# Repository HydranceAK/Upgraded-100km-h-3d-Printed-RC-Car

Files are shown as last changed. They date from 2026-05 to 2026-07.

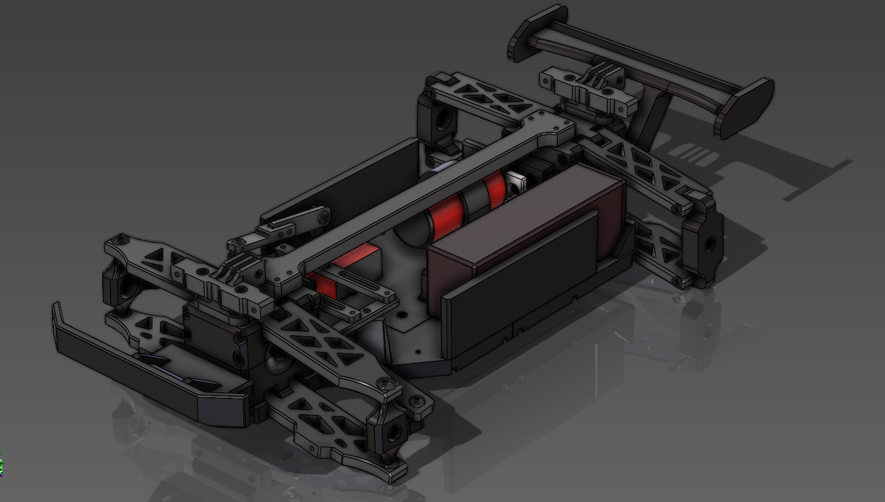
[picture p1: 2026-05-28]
Images/Screenshot 2026-05-28 100129.png

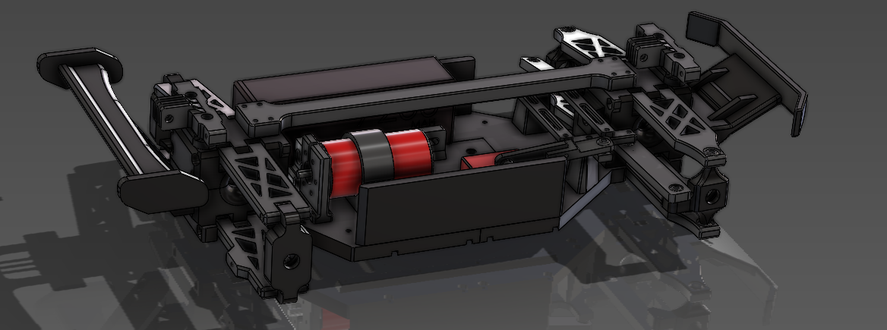
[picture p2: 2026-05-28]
Images/Screenshot 2026-05-28 100137.png

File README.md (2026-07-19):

Designed and engineered by Hydrance.

This is my final and best version of my 3d printed RC Car series. Upgraded with metal differentials, metal axles, improved suspension, 
larger frame, more space for adjustments, and an overall polished and improved design, this will likely be my final attempt at making the perfect 3d printed RC Car.  

This RC Car is nearly have the price to any premade online rc car you will find. This car comes with perks of being completely customizable. All source files are provided for completely free, you can make any changes and share for others to use. You can buy replacements parts for dirt cheap, and print anything for under $0.50 if your car breaks.

Instruction & Assembly Manual: [**LINK TO MANUAL**](https://fanciful-zabaione-62d97d.netlify.app/)

Youtube Video: [**LINK TO YOUTUBE CHANNEL**](https://www.youtube.com/@HydranceYT)

Solidworks and source files are available for purchase on my website: COMING SOON 

_****STABLE RELEASE 3.0****_
_****BETA RELEASE 4.0****_

Patch notes:

- Suspension arms changed, much bulkier, double width
- Wheel hubs adjusted for quality
- Minor changes in axle supporter and battery stopper
- Frame lengthend and thickened
- Stability and strength improved

History of Releases:

- V1 May 21st 2026
- V1.5 May 25th 2026
- V2 May 27th 2026
- V3 June 21st 2026 (only on makerworld)
- V4 June 29th 2026 (UNSTABLE RELEASE, DO NOT PRINT)

Features

-4WD Drivetrain

-Top Speed: - 100km/h (untested as of today)

-Independent Suspension

-Fully metal drive train

-TPU parts for flexible components (tires, dampening mounts, impact zones)

-PETG parts for strong structural elements (chassis, arms, mounts)

**Printing Notes**

-TPU recommended for flexible and shock-absorption components

-PETG recommended for strength, heat resistance, and rigidity

-Everything can be printed on Bambu Lab a1 (0.4 or 0.6 nozzle)

-Hardware, electronics, and drivetrain components sourced Amazon and AliExpress

**Tools you will need**

-Sodering machine or lighter to hear threaded inserts
-Screw Driver
-Cutters
-Pliers

**Disclaimer**

This project is provided for personal use only.

You may not sell, redistribute, upload, or copy this design without direct permission from the creator.

I am not responsible for any damage, injury, or misuse involving this design, its assembly, or its operation.

Operate RC vehicles safely and responsibly.

**Contact**

For permissions, questions, or collaboration, contact me at:

Email: abdusamaku@gmail.com

YouTube: https://youtube.com/@HydranceYT







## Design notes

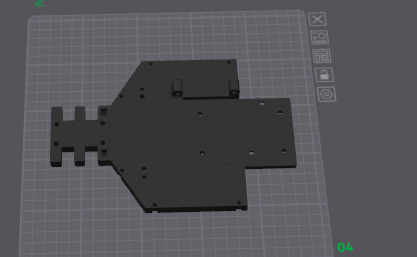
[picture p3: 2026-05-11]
Images/Screenshot 2026-05-07 212240.png

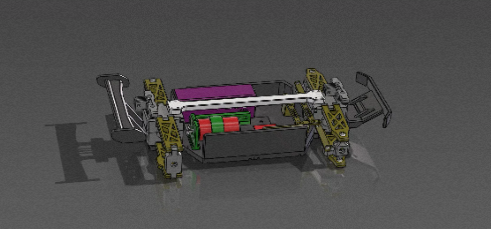
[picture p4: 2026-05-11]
Images/Screenshot 2026-05-11 104807.png

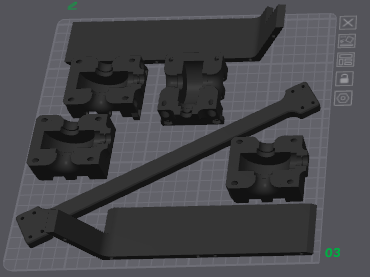
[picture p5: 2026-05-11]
Images/Screenshot 2026-05-07 212237.png

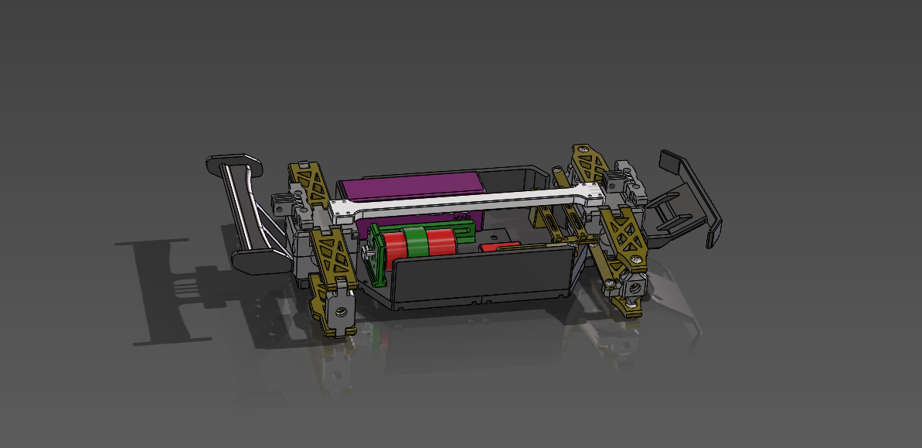
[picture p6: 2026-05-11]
Images/Screenshot 2026-05-07 211917.png

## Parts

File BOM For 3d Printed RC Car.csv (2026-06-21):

Part Name | Quantity | Link | Link 2 | Unit Price (cheaper of the two links) | Total (CAD)
HSP 1:10 RC Car Front Differential Gearbox Assembly for 94111 94123 02051 02030 03015 Models | 1 | https://www.aliexpress.com/item/32785144165.html |  | $11.50 | $11.50
HSP 1:10 RC Car Rear Differential Gearbox Assembly Upgrade Set for 94111 94123 02051 02030 03015 Model | 1 | https://www.aliexpress.com/item/32785144165.html |  | $12.50 | $12.50
Metal 08029 Dogbones 89.5 Drive Shaft | 1 | https://www.amazon.ca/dp/B08SBXVM3T | https://www.aliexpress.com/item/1005005871803520.html | $7.00 | $7.00
Hex Mounts (12mm, 5mm thickness) | 1 | https://www.aliexpress.com/item/1005005581727925.html? |  | $6.00 | $6.00
170mm Central Drive Shaft With Cups | 1 | https://www.aliexpress.com/item/1005002029883656.html | https://www.aliexpress.com/item/1005004008554769.html | $6.00 | $6.00
Spur Gears (21T & 64T) 11184 Steel Metal Spur HSP Car | 1 | https://www.aliexpress.com/item/32852070235.html? | https://www.aliexpress.com/item/1005008726909208.html | $5.00 | $5.00
Motor (2850KV 3670) 3-4S Lipos | 1 | https://www.amazon.ca/GoolRC-S3670-2850KV-Brushless-Sensorless/dp/B08YD792LM |  | $50.00 | $50.00
ESC (120A) 2-3s (60km/h) 2-4s (100km/h) | 1 | https://www.aliexpress.com/item/1005007728846589.html |  | $30.00 | $30.00
Threaded Inserts (m2, m3, m4 sets) | 1 | https://www.amazon.ca/Heat-Set-Threaded-Inserts-Printing-Components/dp/B0DCJ4MXCM |  | $14.00 | $14.00
M4 Screw Assortment | 1 | https://www.amazon.ca/Hilitchi-300-Piece-Phillips-Assortment-stainless/dp/B01N4HPO2D |  | $12.00 | $12.00
M3 Screw Assortment | 1 | https://www.amazon.ca/gp/product/B01NBOCXHE |  | $12.00 | $12.00
INJORA RC Transmitter 2.4GHz 6CH Controler and Receiver | 1 | https://www.amazon.ca/INJORA-Transmitter-Controler-Receiver-Crawler/dp/B08SJW1TMC | https://www.aliexpress.com/item/1005005214765667.html | $30.00 | $30.00
3s LIPO PURCHASE 4S FOR HIGHER POWER | 1 | https://www.amazon.ca/Zeee-Connector-Airplane-Helicopter-Quadcopter/dp/B0BZ46JRGJ | https://www.aliexpress.com/item/1005009205837699.html | $20.00 | $20.00
Servo Motor (20kg) MG996R | 1 | https://www.amazon.ca/dp/B0769DFJVK | https://www.aliexpress.com/item/1005007792248497.html | $11.00 | $11.00
10x15x4 bearings | 1 | https://www.amazon.ca/dp/B08B13CZR7?ref= | https://www.aliexpress.com/item/1005007526461474.html? | $7.00 | $7.00
5x10x4 bearings | 1 | https://www.amazon.ca/gp/product/B0C74XL9Y9/ref= | https://www.aliexpress.com/item/1005006890349365.html? | $5.00 | $5.00
130mm Tires | 1 | https://www.amazon.ca/Scale-Monster-Tires-Gravel-Spokes/dp/B01DU4N8YM/ref=s |  | $26.00 | $26.00
100mm Shock Absorbers | 1 | https://www.aliexpress.com/item/1005004264007439.html | https://www.amazon.ca/Podazz-Absorber-Crawler-Dual-Stage-AXI231017/dp/B0DCZBS7HD/ref | $12.00 | $12.00
M4 Long Screws | 1 | https://www.amazon.ca/NIULUNBAO-Socket-Machine-Threaded-Assortment/dp/B0BJQ28WX7/ref |  | $14.00 | $14.00
10x20x6 bearings | 1 | https://www.amazon.ca/uxcell-MR2010ZZ-Groove-Bearings-Shielded/dp/B09F39CVQ6/ |  | $12.00 | $12.00
 |  |  |  |  | $291.00
 |  |  |  |  | $234 USD

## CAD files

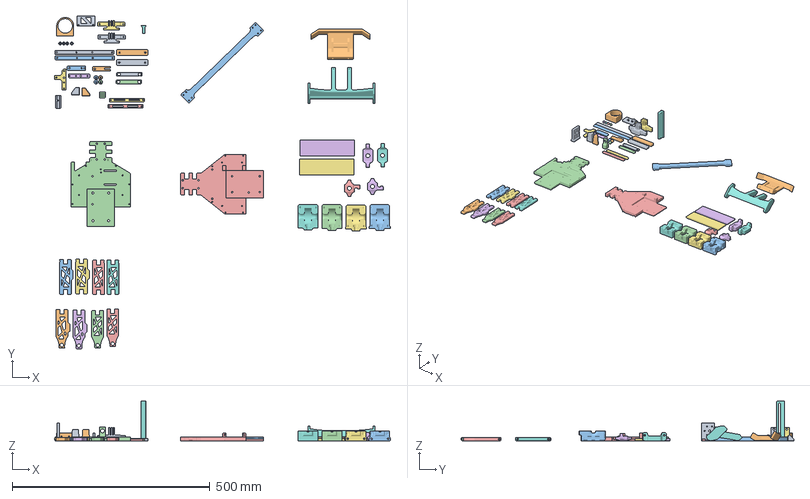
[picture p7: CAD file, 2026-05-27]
3dPrintedRCCar100kmh V2.3mf
850.3 x 841.6 x 100.0 mm
Battery-Stopper.STEP
Upgraded Bumper.STEP
Frame-Strengthener.STEP
Frame-Rear.STEP
Frame-Front.STEP
Frame Railing Left.STEP
Frame Railing.STEP
Frame-Battery-Splitter.STEP
Frame-Strengthener-Bottom.STEP x 2
Front-Bottom-Suspension-Arm.STEP x 2
Front-Suspension-Arm-Ball.STEP x 4
Front-Top-Suspension-Arm.STEP x 2
Front-Wheel-Hub-Left.STEP
Front-Wheel-Hub-Right.STEP
Gearbox - Top.STEP x 2
Gearbox.STEP x 2
Motor-Mount.STEP
Motor-Support.STEP
Rear-Bottom-Suspension-Arm.STEP x 2
Rear-Gearbox-Axle-Support.STEP
Rear-Top-Suspension-Arm.STEP x 2
Rear-Wheel-Hub.STEP x 2
Shock-Mount.STEP x 2
Spoiler.STEP
Steering Arm.STEP x 2
Steering Servo Arm #1.STEP
Steering Servo Arm #2.STEP
Steering-Arm.STEP x 2
Steering-Arm-Balancer.STEP x 2
Steering-Arm-Post-Left.STEP
Steering-Arm-Post-Right.STEP
Steering-Ball.STEP x 4
Steering-Post-Left.STEP
Steering-Post-Right.STEP

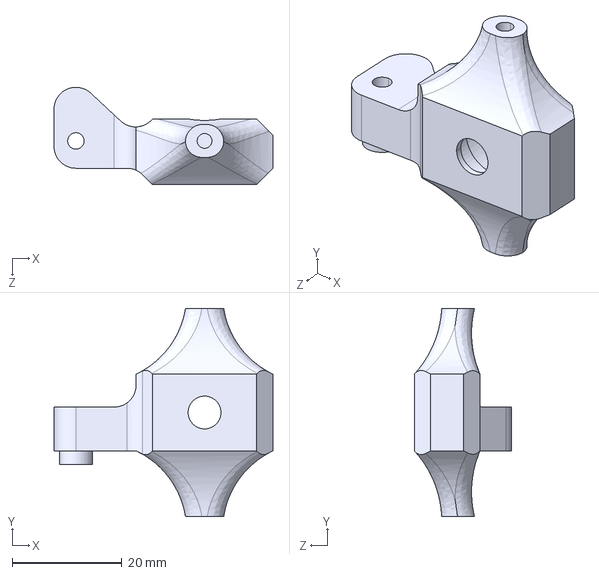
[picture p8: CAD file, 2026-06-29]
STEP Files/Front-Wheel-Hub-Left.STEP
40.0 x 38.0 x 17.8 mm

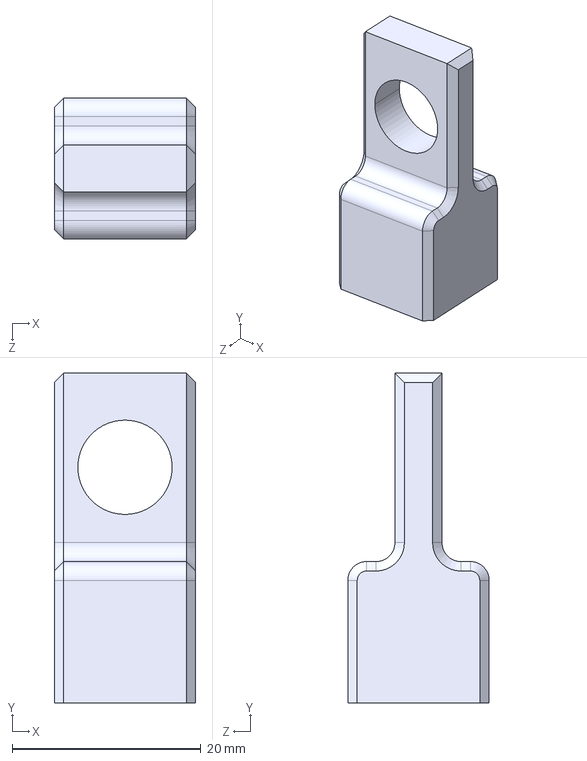
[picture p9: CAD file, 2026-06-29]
STEP Files/Rear-Gearbox-Axle-Support.STEP
15.0 x 35.0 x 15.0 mm

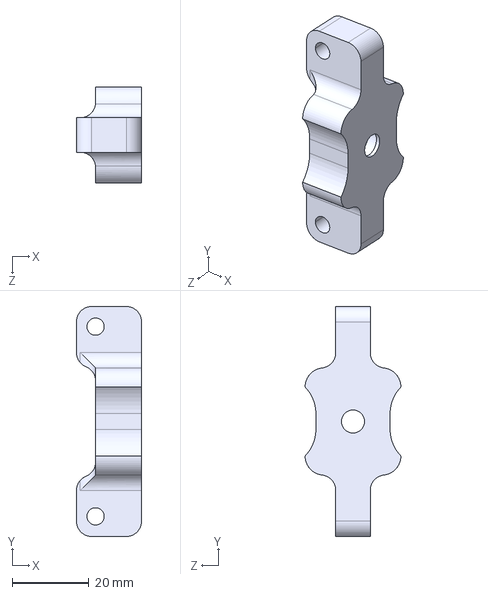
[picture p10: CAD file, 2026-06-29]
STEP Files/Rear-Wheel-Hub.STEP
17.0 x 60.0 x 25.0 mm

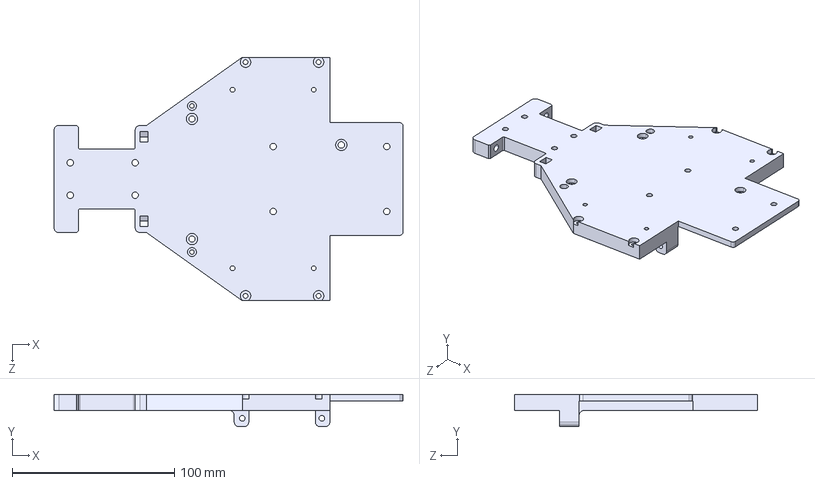
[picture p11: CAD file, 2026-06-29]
STEP Files/Frame-Front.STEP
215.0 x 20.0 x 150.0 mm

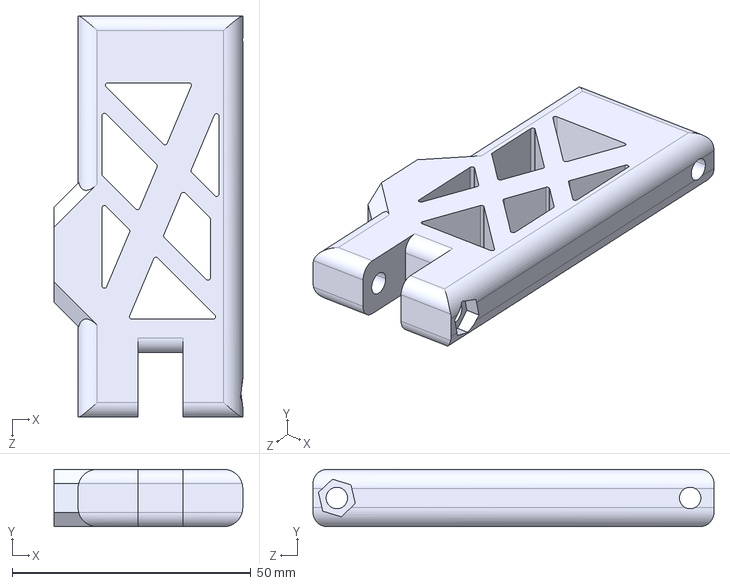
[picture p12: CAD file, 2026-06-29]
STEP Files/Rear-Bottom-Suspension-Arm.STEP
39.5 x 12.0 x 84.0 mm

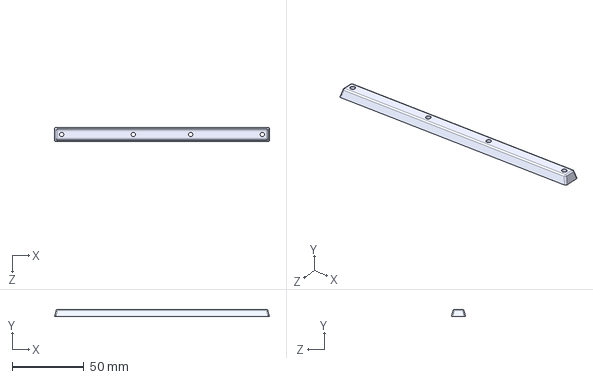
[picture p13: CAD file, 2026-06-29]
STEP Files/Frame-Strengthener-Bottom.STEP
150.0 x 5.00 x 10.0 mm

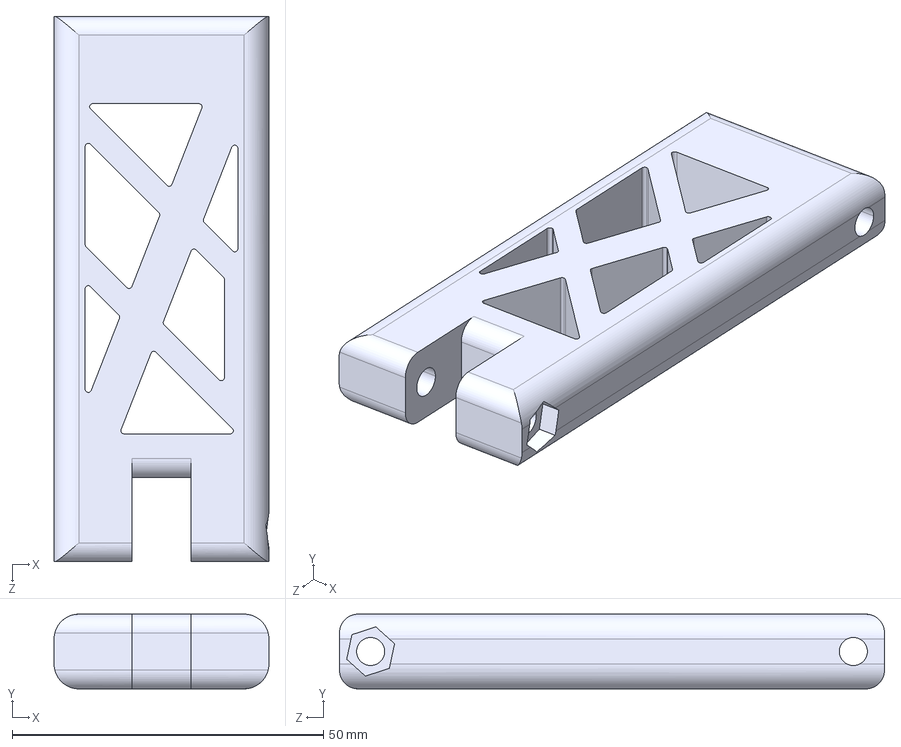
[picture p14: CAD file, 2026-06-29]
STEP Files/Rear-Top-Suspension-Arm.STEP
34.5 x 12.0 x 87.5 mm

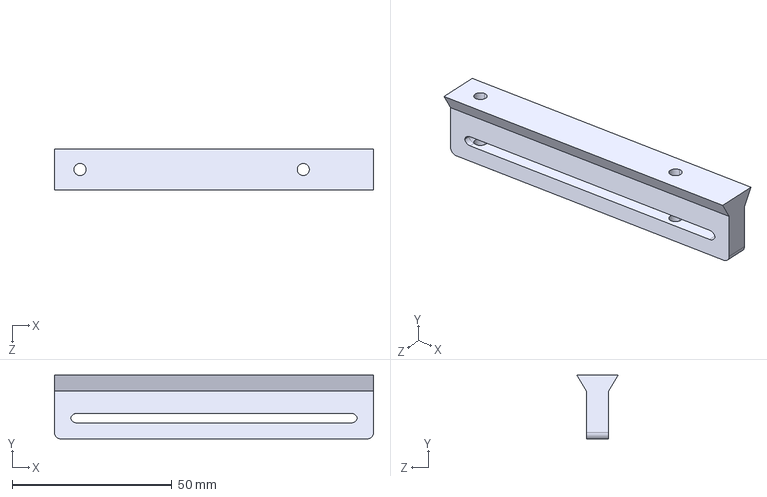
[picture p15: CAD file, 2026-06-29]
STEP Files/Frame-Battery-Splitter.STEP
100.0 x 20.0 x 13.0 mm

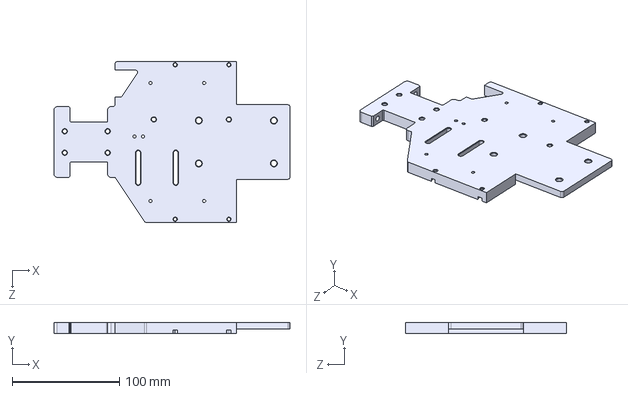
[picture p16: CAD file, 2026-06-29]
STEP Files/Frame-Rear.STEP
220.0 x 10.0 x 150.0 mm

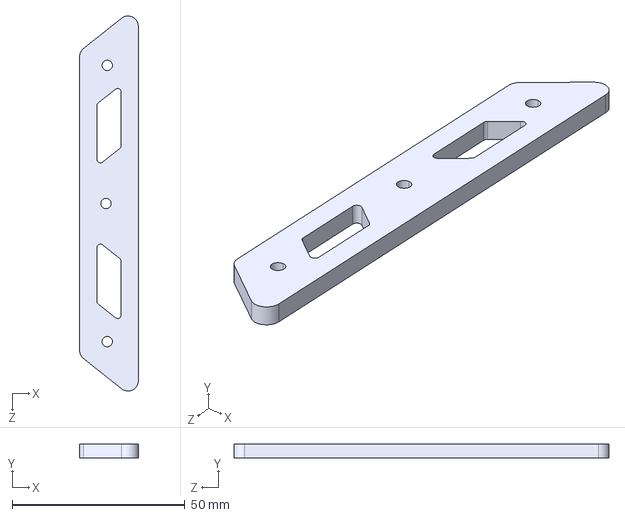
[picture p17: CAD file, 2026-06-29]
STEP Files/Steering Posts Top.STEP
17.0 x 4.00 x 108.6 mm

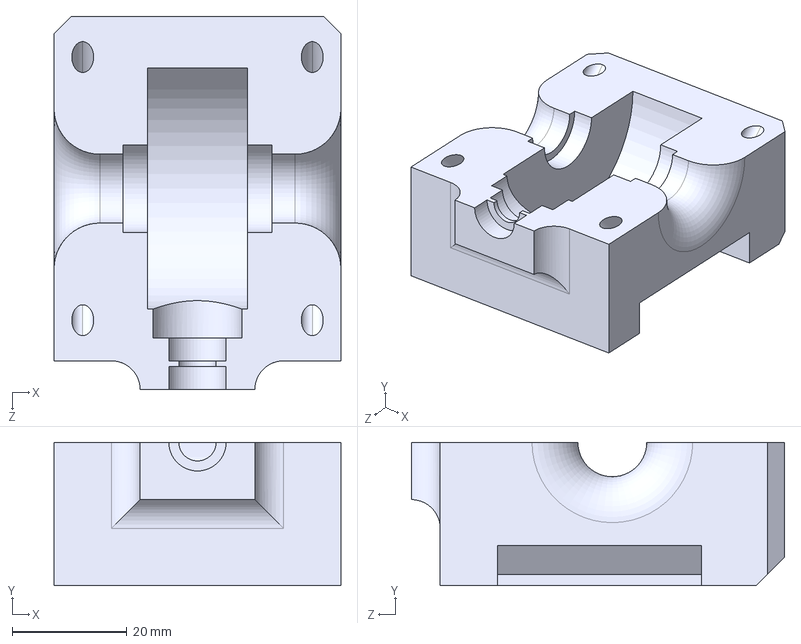
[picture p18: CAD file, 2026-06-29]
STEP Files/Gearbox.STEP
50.0 x 25.0 x 65.0 mm

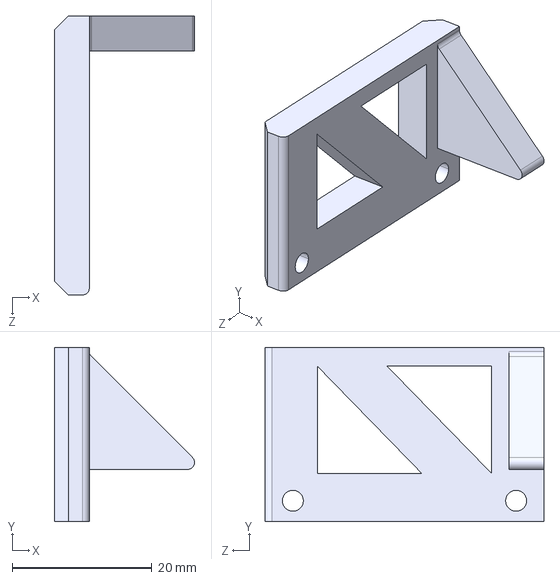
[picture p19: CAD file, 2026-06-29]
STEP Files/Battery-Stopper.STEP
20.1 x 25.0 x 40.0 mm

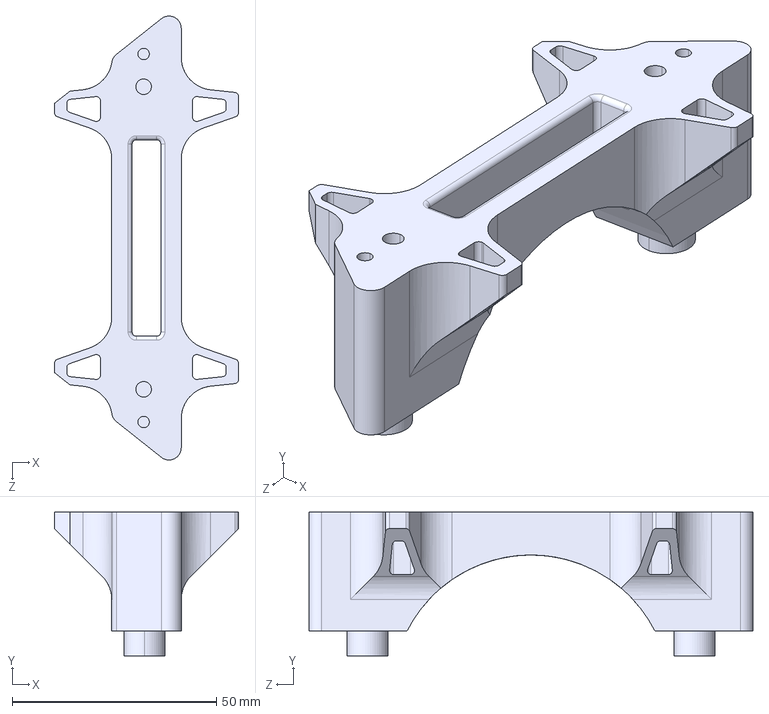
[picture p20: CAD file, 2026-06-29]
STEP Files/Steering Posts.STEP
45.0 x 35.1 x 108.6 mm

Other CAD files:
STEP Files/Steering Arm.STEP
STEP Files/Front-Wheel-Hub-Right.STEP
STEP Files/Gearbox - Top.STEP
STEP Files/Steering-Arm-Balancer.STEP
STEP Files/Frame Railing Left.STEP
STEP Files/Frame Railing.STEP
STEP Files/Frame-Strengthener.STEP
STEP Files/Motor-Mount.STEP
STEP Files/Motor-Support.STEP
STEP Files/Shock-Mount.STEP
STEP Files/Spoiler.STEP
STEP Files/Steeering-Arm.STEP
STEP Files/Steering Servo Arm #1.STEP
STEP Files/Steering Servo Arm #2.STEP
STEP Files/Steering-Arm-Post-Left.STEP
STEP Files/Steering-Arm-Post-Right.STEP
STEP Files/Steering-Arm.STEP
STEP Files/Steering-Servo-Arm.STEP
STEP Files/Upgraded Bumper.STEP

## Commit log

2026-05-15 Add files via upload
    Final BOM. No foreseeable changes other than failed links replacement.
    [BOM For 3d Printed RC Car - Sheet1.csv]
2026-05-20 Stable Release 1.0
    This is the first stable release 1.0 of the 90km/h 3d Printed RC Car.
    [3sLipoBattery.SLDPRT, Battery-Stopper.SLDPRT, Frame Railing Left.SLDPRT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]
2026-05-27 Add files via upload
    V2 Files, May 27th 2026.
    [Frame Railing Left.STEP, Frame Railing.STEP, Frame-Front.STEP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]
2026-05-27 Delete STEP Files/Front Suspension Arm Bottom.STEP
    Incorrect file version removed
    [Front Suspension Arm Bottom.STEP]
2026-05-27 Delete STEP Files/Front Suspension Arm Top.STEP
    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
    [Front Suspension Arm Top.STEP]
2026-06-03 Added updated components
    Some parts were updated, minor bugs removed.
    [Front-Bottom-Suspension-Arm Right.STEP, Front-Bottom-Suspension-Arm.STEP, Front-Top-Suspension-Arm.STEP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]
2026-06-21 Update BOM For 3d Printed RC Car.csv
    [BOM For 3d Printed RC Car.csv]
2026-06-29 Delete STEP Files directory
    Deleting to upload V4 Files
    [Battery-Stopper.STEP, Frame Railing Left.STEP, Frame Railing.STEP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]
2026-06-29 Uploaded V4 BETA Files
    This is V4 beta files, untested.
    [Battery-Stopper.STEP, Frame Railing Left.STEP, Frame Railing.STEP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]
